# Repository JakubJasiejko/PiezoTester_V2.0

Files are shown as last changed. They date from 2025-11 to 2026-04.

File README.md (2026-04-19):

# PiezoTester V2.0

PiezoTester V2.0 is a custom mechatronic test platform for piezoresistive and piezoelectric sensor evaluation under repeatable electromagnetic loading. The project combines an ESP32-based real-time firmware stack, a desktop control application, custom electronics, and mechanical fixtures into one reproducible research toolchain.

It is not just a “demo rig”. It is a full test bench with closed-loop load estimation, sensor-path calibration, adaptive electromagnet characterization, automated reporting, and hardware revision tracking.

## Why This Repository Matters

PiezoTester V2.0 was built to make experimental work faster, cleaner, and more defensible:

- Repeatable cyclic load generation using an electromagnet-driven actuator
- Real-time acquisition of load-cell and piezoresistive sensor data
- Calibration workflows aligned with the actual firmware implementation
- Adaptive PWM-to-load learning for feedforward-assisted ramp tests
- Standard, ramp, and hysteresis test modes
- Desktop export pipeline for CSV and PDF reports
- Versioned PCB and CAD assets kept next to the code that drives them

## Project Structure

```text
PiezoTester_V2.0/
├── firmware/         ESP32 firmware (ESP-IDF, C)
├── desktop_app/      Desktop control and reporting application (Python, PySide6)
├── hardware/
│   ├── PCB/          KiCad projects, board revisions, fabrication outputs
│   └── CAD/          Mechanical CAD parts and assemblies
├── sample_results/   Example CSV/PDF outputs generated by the system
├── docs/             Cross-project documentation, asset sources, image placeholders
├── LICENSE
└── README.md
```

## Core Features

- Multi-mode testing: standard, ramp, and hysteresis acquisition
- One-point load-cell calibration with nominal model correction
- Sensor-path resistance calibration using a reference resistor
- Continuous live mass preview in the calibration workflow
- Advanced electromagnet contact calibration with stored contact-state tables
- Learned PWM-to-load map with point insertion, sorting, interpolation, and reuse
- Feedforward-assisted ramp control with bounded correction steps
- Automatic test summary generation with CSV/PDF export support
- Hardware revision history covering PCB and mechanical development

## Technical Highlights

- Nominal load-cell model based on beam capacity, sensitivity, excitation voltage, and analog gain
- Absolute-value load signal handling to avoid negative mass artifacts
- Resistance reconstruction from divider voltage with a calibration factor stored in NVS
- Electromagnet premodel derived from movement/contact thresholds
- Learned actuator model stored as empirical `(PWM, mass)` pairs
- Piecewise-linear feedforward estimate for ramp tests
- Iterative predictive-corrective update in the ramp controller
- Burst acquisition for hysteresis traces at high sample rate

## Recent Project Wins

- A research-grade calibration flow that mirrors the actual firmware math
- On-device learning of electromagnet behavior instead of fixed lookup-only control
- Integrated desktop reporting that produces presentation-ready PDF summaries
- Multiple PCB revisions with local symbol, footprint, and 3D asset preservation
- A repository structure now being shaped to support publication, fabrication, and onboarding

## Visuals

Add your best visuals here and the repository will immediately look much more “product-level”.

### Hero Shot

PiezoTester hero shot

_Suggested image: full assembled device on bench, powered on, with the desktop UI visible in the background._

### Desktop Application

Desktop application screenshot

_Suggested image: the main control window with charts, statistics, and connection status._

### PCB Render

PCB render

_Suggested image: 3D render of the latest board revision in KiCad._

### Mechanical Assembly

Mechanical assembly

_Suggested image: CAD assembly or the real fixture with the load cell, electromagnet, and specimen stage._

## Getting Started

### Firmware

See [firmware/README.md](firmware/README.md) for build, flash, and architecture details.

### Desktop Application

See [desktop_app/README.md](desktop_app/README.md) for runtime requirements, launch instructions, and export workflow notes.

### Hardware

See:

- [hardware/README.md](hardware/README.md)
- [hardware/PCB/README.md](hardware/PCB/README.md)
- [hardware/CAD/README.md](hardware/CAD/README.md)

## Asset Sources and Dependencies

The repository intentionally keeps third-party footprint/model provenance visible instead of burying it in tool-generated files.

See:

- [docs/README.md](docs/README.md)
- [docs/THIRD_PARTY_SOURCES.md](docs/THIRD_PARTY_SOURCES.md)

## Sample Outputs

Representative test artifacts are stored in [sample_results/README.md](sample_results/README.md).

## Self-Praise, Because It Is Earned

This project is a serious piece of interdisciplinary work:

- Embedded systems
- measurement engineering
- mechatronic actuation
- hardware design
- desktop tooling
- experimental workflow design

That combination is hard to execute well, and PiezoTester V2.0 already shows a lot more systems thinking than a typical “lab side-project”. It deserves to look the part.

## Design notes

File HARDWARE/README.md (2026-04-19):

# Hardware

This directory contains the physical implementation of PiezoTester V2.0: electronics, PCB revisions, and mechanical CAD.

## Scope

- Measurement electronics
- Actuator-drive electronics
- PCB revision history
- Local KiCad symbol, footprint, and 3D assets
- Mechanical fixture and assembly parts

## Subdirectories

- [PCB/README.md](PCB/README.md)
  KiCad projects, fabrication outputs, local libraries, and revision-specific notes.
- [CAD/README.md](CAD/README.md)
  Mechanical parts and assembly files used to build the test fixture.

## Design Philosophy

The hardware side of this repository is treated as a first-class engineering asset rather than a binary dump. Board revisions, local libraries, and CAD files are intentionally kept close to the firmware and desktop software so the full system stays reproducible.

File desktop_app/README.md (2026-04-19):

# Desktop Application

This directory contains the host-side control software for PiezoTester V2.0. The application is written in Python with PySide6 and acts as the main user interface for calibration, live monitoring, test execution, charting, and report export.

## Features

- Serial-device discovery and connection handling
- Live mass preview during calibration
- Standard, ramp, and hysteresis test control
- Electromagnet advanced calibration workflows
- Interactive result tables and multi-chart views
- CSV export for raw session data
- PDF export for polished experiment summaries
- Optional operator notes included in the generated report

## Runtime Dependencies

- Python 3.11+
- PySide6
- pyserial

Install the dependencies with:

```bash
cd desktop_app
python3 -m venv .venv
source .venv/bin/activate
pip install -r requirements.txt
```

## Launch

```bash
cd desktop_app
python3 main.py
```

## Important Subfolders

- `logs/`
  Local session outputs generated during development and bench testing.
- `.venv/`
  Local virtual environment, intentionally ignored by Git.
- `.idea/`
  Local IDE metadata, intentionally ignored by Git.

## Notes

- The application expects the ESP32 firmware UART protocol defined in `firmware/main/main.c`.
- Exported reports are intentionally stored as regular files so they can be attached to experiments, papers, and manufacturing validation records.

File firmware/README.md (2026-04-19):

# Firmware

This directory contains the ESP32 firmware for PiezoTester V2.0. It is built with ESP-IDF and implements the real-time measurement, calibration, electromagnet control, session logic, and UART command interface used by the desktop application.

## What This Firmware Does

- Reads the ADS1219-based load path
- Reconstructs piezoresistive sensor resistance
- Calibrates the load cell and the sensor path
- Drives the electromagnet through PWM
- Learns an empirical PWM-to-load model
- Executes standard, ramp, and hysteresis tests
- Stores calibration data and learned model points in NVS
- Streams results and status to the host application over UART

## Key Capabilities

- Load preview with automatic tare initialization
- One-point load-cell calibration with nominal-model correction
- Reference-resistor calibration for the sensor measurement path
- Contact-threshold and movement-threshold learning for the electromagnet
- Adaptive ramp targeting with feedforward plus bounded correction
- Hysteresis trace acquisition at high sample rate
- Export-friendly UART protocol for the desktop application

## Main Source Files

```text
firmware/
├── CMakeLists.txt
├── sdkconfig
└── main/
    ├── main.c        Application logic, test controller, calibration, learning
    ├── ads1219.c/h   ADS1219 ADC driver
    ├── i2c.c/h       I2C transport helpers
    ├── uart.c/h      UART transport helpers
    ├── spi.c/h       SPI helpers used by board support code
    └── adg731.c/h    ADG731 channel switch helper
```

## Build

```bash
cd firmware
idf.py build
```

## Flash

```bash
cd firmware
idf.py -p /dev/ttyUSB0 flash monitor
```

Adjust the serial port to match your machine.

## Firmware Architecture

The firmware centers around three coupled subsystems:

1. Measurement subsystem
   Captures load and sensor-path voltages, converts them to calibrated engineering units, and returns structured test results.

2. Calibration and learning subsystem
   Maintains load-cell calibration, sensor-path calibration, electromagnet thresholds, and the learned PWM-to-load map in NVS.

3. Test execution subsystem
   Runs measurement sessions in standard, ramp, and hysteresis modes while keeping the UART interface deterministic for the desktop application.

## Mathematical / Algorithmic Notes

- Load signal is computed from the absolute difference between zero and measured voltage.
- Load-cell calibration uses a nominal physical model corrected by a one-point scaling factor.
- Sensor resistance is reconstructed from divider voltage and corrected by a calibration factor.
- Ramp control uses:
  - a feedforward estimate from the learned actuator model
  - an iterative correction loop with bounded PWM step size
- Hysteresis acquisition uses burst-style high-rate sampling across loading and unloading phases.

## Documentation Quality

The firmware headers and main application source are being annotated with Doxygen-style comments so the codebase can be turned into browsable technical documentation later.

## Notes About Legacy / Generated Files

This repository has been actively used during hardware bring-up. Some generated or legacy files still exist for traceability, but they are now documented and increasingly fenced off by `.gitignore` rules and folder-level README files.

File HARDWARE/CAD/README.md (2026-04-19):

# CAD

This directory contains the mechanical design assets for PiezoTester V2.0.

## Contents

- SolidWorks part files (`.SLDPRT`)
- SolidWorks assembly files (`.SLDASM`)
- STEP exports for exchange and review

## Typical Parts

- Electromagnet mounting hardware
- Structural profiles and fixture supports
- Table / specimen support geometry
- Load-cell support parts
- Contact and pressure-transfer parts

## Intent

The CAD side of the project documents how the electrical and sensing stack is physically realized. These files are essential to understanding:

- specimen alignment
- force transmission path
- load-cell mounting
- electromagnet positioning
- fixture repeatability

## Exchange-Friendly Files

Where STEP files are present, they should be treated as the preferred review / sharing format for collaborators who do not use SolidWorks.

## Local Authoring Note

Most files in this folder are project-authored mechanical assets rather than third-party vendor downloads. When a neutral exchange export exists, it is kept next to the native CAD source on purpose.

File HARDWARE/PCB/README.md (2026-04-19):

# PCB

This directory stores the electrical design history of PiezoTester V2.0 in KiCad.

## Available Revisions

- `PCB V2.0`
  Early board revision and legacy project assets.
- `PCB V2.1`
  Intermediate revision with local 3D model integration.
- `PCB V2.2`
  Later revision with fabrication outputs and local symbol / footprint libraries.

## What You Will Find Here

- `.kicad_pro`, `.kicad_sch`, `.kicad_pcb` source files
- Local symbol and footprint libraries
- Local 3D models used by KiCad
- Gerber exports and production artifacts
- Revision-specific backup archives generated by KiCad

## Source Provenance

This repository mixes:

- custom project-specific KiCad symbols and footprints
- vendor-derived assets from SamacSys-style libraries
- SparkFun and Espressif-derived reference models for selected modules
- local fixes applied so 3D models resolve directly from the repository

See [../../docs/THIRD_PARTY_SOURCES.md](../../docs/THIRD_PARTY_SOURCES.md) for the documented origin of the main assets.

## Practical Note

KiCad creates autosaves, lock files, cache files, and backups aggressively during active design sessions. The repository now documents these artifacts explicitly and ignores the transient ones where possible, while preserving revision history that is actually useful.

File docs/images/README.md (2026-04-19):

# README Image Placeholders

Place repository-facing visuals here.

Recommended files:

- `hero-shot.jpg`
- `desktop-app-screenshot.png`
- `pcb-render.png`
- `mechanical-assembly.png`

These names are already referenced by the top-level `README.md`.

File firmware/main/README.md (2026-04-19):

# Firmware Main Module

This folder contains the application-layer firmware sources for PiezoTester V2.0.

## File Responsibilities

- `main.c`
  High-level application logic, calibration workflow, test execution, UART command handling, actuator learning, and NVS persistence
- `ads1219.c/h`
  ADS1219 ADC transport and conversion control
- `i2c.c/h`
  I2C bus helper layer
- `uart.c/h`
  UART helper layer
- `spi.c/h`
  SPI helper layer used by board support code
- `adg731.c/h`
  ADG731 switching helper

## Documentation Style

This folder is being annotated with Doxygen-style comments so the firmware can later be published as browsable API / implementation documentation.

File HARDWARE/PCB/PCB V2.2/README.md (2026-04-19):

# PCB V2.2

This folder contains a later and more production-oriented board revision for PiezoTester V2.0.

## Highlights

- Expanded local footprint and symbol libraries
- Local 3D model assets kept inside the repository
- Fabrication outputs for manufacturing
- JLCPCB BOM / CPL generation support

## Main Project Path

- `piezoTester v2.2/piezoTester v2.2.kicad_pro`

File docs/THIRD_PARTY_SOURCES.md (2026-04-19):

# Third-Party Sources and Dependency Notes

This document records the main external building blocks used in PiezoTester V2.0 so the repository stays traceable and publication-friendly.

## Firmware Dependencies

### ESP-IDF

- Role: primary embedded framework for ESP32 firmware
- Usage: GPIO, LEDC PWM, UART, I2C, SPI, NVS, timing, FreeRTOS integration
- Project location: `firmware/`

The firmware currently uses ESP-IDF-native drivers and in-repo application code. There are no separate Git submodules for third-party C libraries in active use at the moment.

## Desktop Application Dependencies

### PySide6

- Role: GUI framework for charts, dialogs, tables, PDF generation, and plotting UI
- Project location: `desktop_app/main.py`

### pyserial

- Role: serial communication with the ESP32 firmware
- Project location: `desktop_app/main.py`

## PCB Libraries and Model Sources

### SamacSys-generated libraries

Several local KiCad symbol / footprint libraries clearly identify themselves with:

- `generator SamacSys_ECAD_Model`

These are used in multiple board revisions and vendor-part library folders, including parts such as:

- LM358P
- MCP6002-I/P
- LM2596S-5.0/NOPB
- LP2950-33LPRE3
- ADS1219IPWR
- CP2102N
- ESP32-WROOM module libraries

These assets are kept locally so the PCB project remains portable and self-contained.

### SparkFun ADS1219 reference material

The repository also uses ADS1219-related reference geometry derived from the SparkFun Qwiic ADC ADS1219 board ecosystem for modeling / representation purposes.

### Espressif reference assets

ESP32-related 3D and module assets were aligned using Espressif reference materials and repository-local model files where required.

### Local project-specific assets

Some 3D files, symbol libraries, and KiCad project libraries were authored or adjusted directly inside the project so that:

- board renders open without missing 3D files
- library dependencies remain repository-local
- revision snapshots stay reproducible

## CAD Sources

The mechanical CAD folder primarily contains project-authored SolidWorks models plus exchange-friendly STEP exports created during device design and fixture iteration.

## Fabrication / Production Outputs

Some PCB revisions contain fabrication-ready exports such as:

- Gerber archives
- drill files
- JLCPCB BOM / CPL outputs

Those files are treated as build artifacts for manufacturing, not as the canonical source. The canonical source remains the KiCad project for the relevant board revision.

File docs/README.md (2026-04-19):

# Documentation

This directory groups repository-level documentation that does not belong to a single code or hardware subfolder.

## Included Documents

- `THIRD_PARTY_SOURCES.md`
  Source provenance for firmware dependencies, PCB assets, and 3D models
- `images/`
  Placeholder location for README visuals and publication-supporting screenshots

## Goal

Make the project easier to:

- present
- publish
- hand off
- review
- reproduce

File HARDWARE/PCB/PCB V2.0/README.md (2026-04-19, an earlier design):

# PCB V2.0

This folder contains an early KiCad revision of the PiezoTester electronics.

## Notes

- Useful as a historical design reference
- Contains local part libraries and early fabrication artifacts
- Includes KiCad-generated backups and autosave traces from active iteration

## Canonical Files

- `urzadzenie_badawcze_V2.kicad_pro`
- `urzadzenie_badawcze_V2.kicad_sch`
- `urzadzenie_badawcze_V2.kicad_pcb`

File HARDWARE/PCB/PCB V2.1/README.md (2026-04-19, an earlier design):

# PCB V2.1

This folder contains the intermediate PiezoTester PCB revision centered on the `piezotesterV2.1` KiCad project.

## Highlights

- Local 3D model integration for board visualization
- Project-local symbol assets
- Gerber export snapshots
- KiCad revision backups

## Main Project Path

- `piezotesterV2.1/piezotesterV2.1.kicad_pro`

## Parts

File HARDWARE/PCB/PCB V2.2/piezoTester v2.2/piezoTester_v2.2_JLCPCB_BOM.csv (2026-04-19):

Comment | Designator | Footprint | LCSC Part # | Quantity | Manufacturer | Manufacturer Part Number | JLC Footprint | Mouser Part Number
LED | 3V3_LED1 | LED_SMD:LED_1206_3216Metric_Pad1.42x1.75mm_HandSolder |  | 1
Barrel_Jack | 12VDC_IN1 | Connector_BarrelJack:BarrelJack_Wuerth_694108106102_2.5x5.5mm |  | 1
R 0 | AIN3 | Resistor_SMD:R_0603_1608Metric_Pad0.98x0.95mm_HandSolder |  | 1
C 22uF | C3 | Capacitor_SMD:C_1206_3216Metric_Pad1.33x1.80mm_HandSolder |  | 1
C 100nF | C4,C6,C10,C12,C28 | Capacitor_SMD:C_1206_3216Metric_Pad1.33x1.80mm_HandSolder |  | 5
C 10uF | C5 | Capacitor_SMD:C_1206_3216Metric_Pad1.33x1.80mm_HandSolder |  | 1
C 1uF | C7,C33 | Capacitor_SMD:C_1206_3216Metric_Pad1.33x1.80mm_HandSolder |  | 2
C 100nF | C8,C14,C16,C17,C20 | Capacitor_SMD:C_0603_1608Metric_Pad1.08x0.95mm_HandSolder |  | 5
C 10uF | C9 | Capacitor_SMD:C_0603_1608Metric_Pad1.08x0.95mm_HandSolder |  | 1
C 1uF | C15,C18,C19,C21 | Capacitor_SMD:C_0603_1608Metric_Pad1.08x0.95mm_HandSolder |  | 4
C 0.1 uF | C22,C23,C24,C25,C26 | Capacitor_SMD:C_0603_1608Metric_Pad1.08x0.95mm_HandSolder |  | 5
C 0.1 uF | C27,C29,C30 | Capacitor_SMD:C_1206_3216Metric_Pad1.33x1.80mm_HandSolder |  | 3
C 1 uF | C31,C32 | Capacitor_SMD:C_0603_1608Metric_Pad1.08x0.95mm_HandSolder |  | 2
ESP32-WROOM-32UE-N16 | ESP32 | 000:ESP32WROOM32UEN16 |  | 1 | Espressif Systems | ESP32-WROOM-32UE-N16
LM2596S-5.0_NOPB | IC3 | ADS1115_Salamon:KTT0005B |  | 1 | Texas Instruments | LM2596S-5.0/NOPB |  | 926-LM2596S-5.0/NOPB
ADS1219IPWR | IC5 | 000:ads1219 |  | 1 | Texas Instruments | ADS1219IPWR |  | 595-ADS1219IPWR
L 68 uH | L1 | Inductor_SMD:L_12x12mm_H6mm |  | 1
R 1K | R2,R3,R20,R22,R23 | Resistor_SMD:R_1206_3216Metric_Pad1.30x1.75mm_HandSolder |  | 5
R 62K | R4,R5 | Resistor_SMD:R_1206_3216Metric_Pad1.30x1.75mm_HandSolder |  | 2
R 1k | R9 | Resistor_SMD:R_1206_3216Metric_Pad1.30x1.75mm_HandSolder |  | 1
R 4.7K | R10 | Resistor_SMD:R_1206_3216Metric_Pad1.30x1.75mm_HandSolder |  | 1
R 10K | R11,R12 | Resistor_SMD:R_1206_3216Metric_Pad1.30x1.75mm_HandSolder |  | 2
R 22 | R13,R14 | Resistor_SMD:R_1206_3216Metric_Pad1.30x1.75mm_HandSolder |  | 2
R 4.7K | R18,R19 | Resistor_SMD:R_0603_1608Metric_Pad0.98x0.95mm_HandSolder |  | 2
R 200K | R21 | Resistor_SMD:R_1206_3216Metric_Pad1.30x1.75mm_HandSolder |  | 1
R 1 | R24 | Resistor_SMD:R_0603_1608Metric_Pad0.98x0.95mm_HandSolder |  | 1
R 680 | R25 | Resistor_SMD:R_1206_3216Metric_Pad1.30x1.75mm_HandSolder |  | 1
R 1 | R26,R27,R28,R29 | Resistor_SMD:R_1206_3216Metric_Pad1.30x1.75mm_HandSolder |  | 4
CH340C | U1 | Package_SO:SOIC-16_3.9x9.9mm_P1.27mm |  | 1

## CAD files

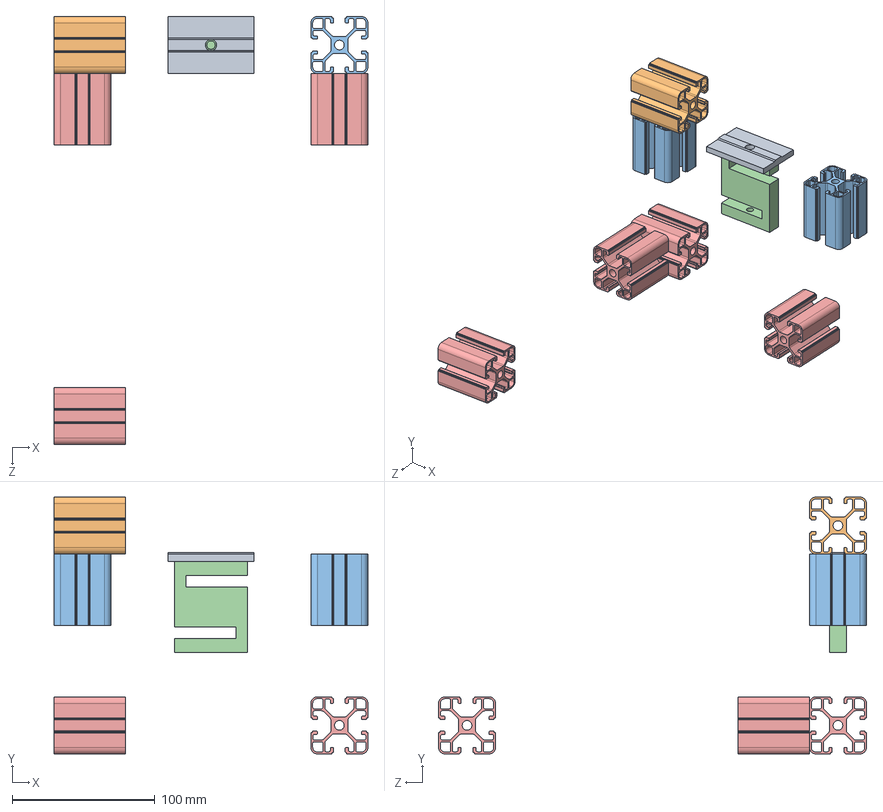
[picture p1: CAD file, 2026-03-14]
HARDWARE/CAD/Złożenie1.SLDASM
220.0 x 180.0 x 300.0 mm
profil_300 x 4
belka_h3C3
profil_rama x 2
profil_nawiercony
stabilizator_belki

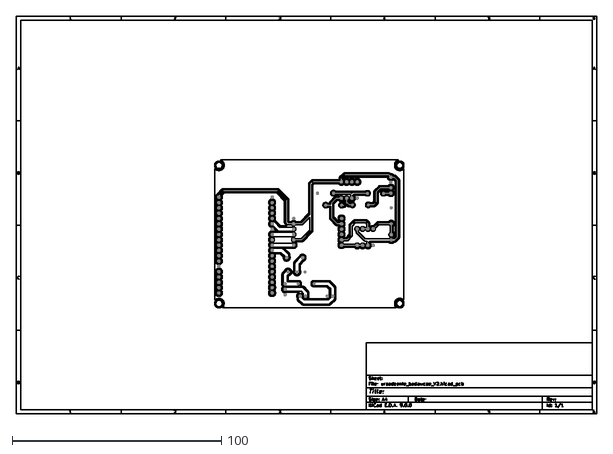
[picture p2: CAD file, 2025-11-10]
firmware/hardware/urzadzenie_badawcze_V2/pcb/urzadzenie_badawcze_V2-F_Cu.dxf
277.0 x 190.0

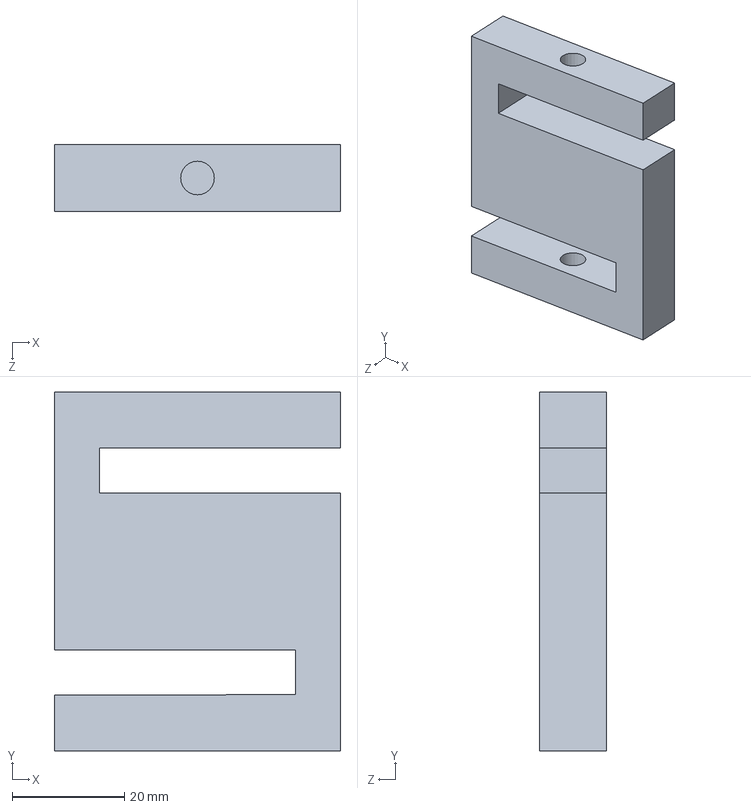
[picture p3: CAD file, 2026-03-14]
HARDWARE/CAD/belka_h3C3.SLDPRT
51.0 x 64.0 x 12.0 mm

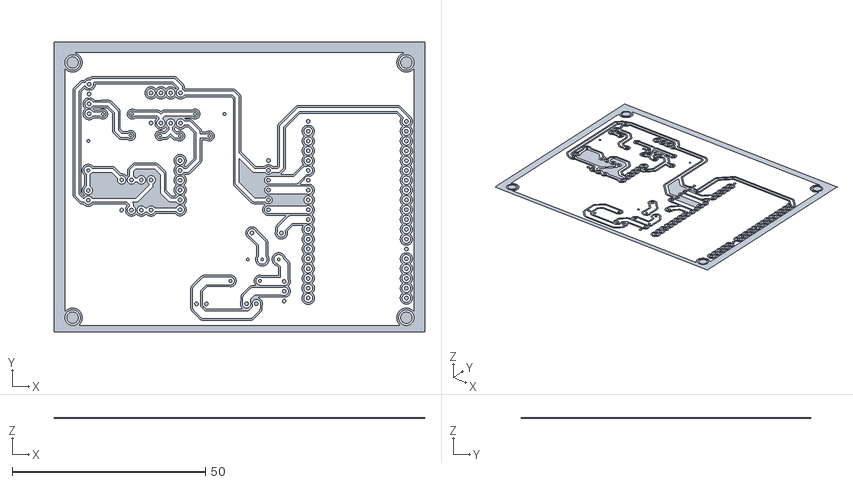
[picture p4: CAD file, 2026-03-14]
hardware/PCB/PCB V2.2/piezoTester v2.2/stl/urzadzenie_badawcze_V2-F_Cu-GOOD.stl
96.0 x 75.0 x 0.05

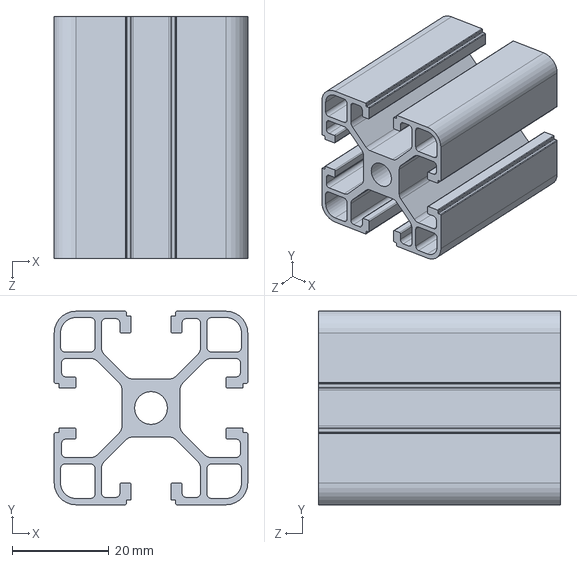
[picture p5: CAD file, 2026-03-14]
HARDWARE/CAD/profil_rama.SLDPRT
40.0 x 40.0 x 50.0 mm

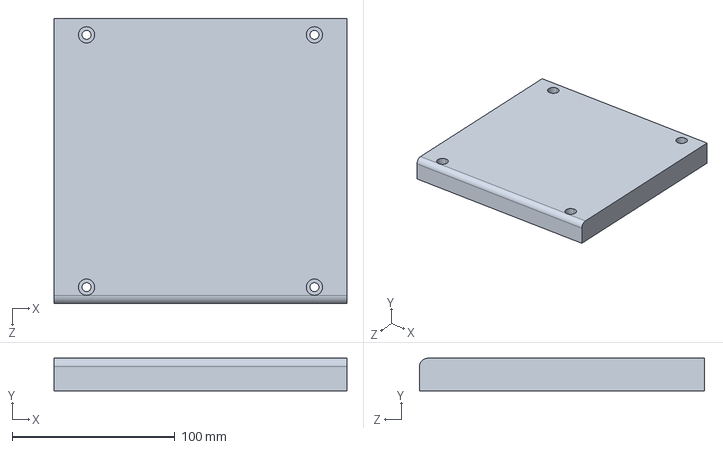
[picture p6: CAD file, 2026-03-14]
HARDWARE/CAD/stolik.STEP
180.0 x 20.0 x 175.0 mm

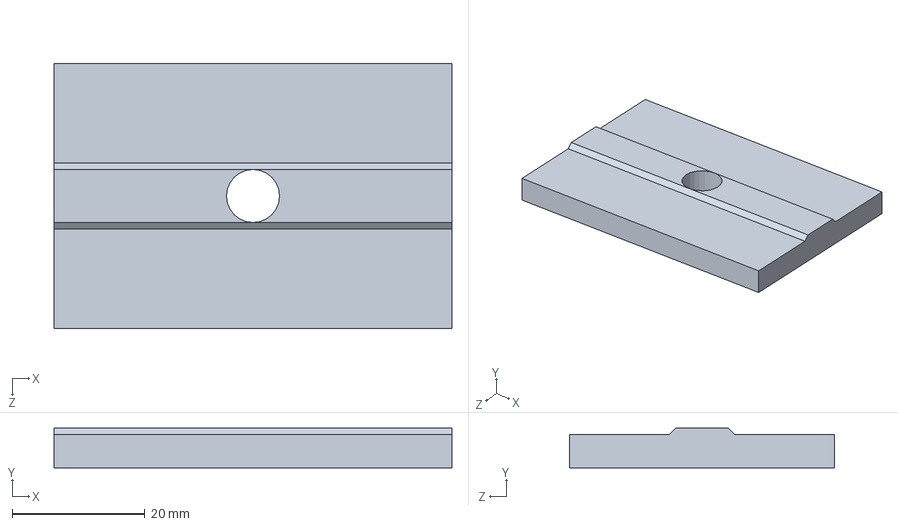
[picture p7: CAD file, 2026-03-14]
HARDWARE/CAD/stabilizator_belki.SLDPRT
60.0 x 6.00 x 40.0 mm

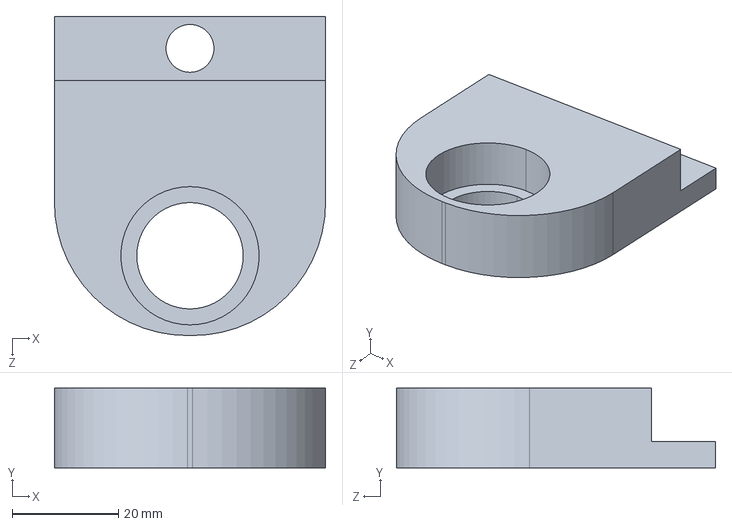
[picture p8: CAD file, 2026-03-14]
HARDWARE/CAD/mocowanie elektromagnesu ofc.STEP
51.0 x 15.0 x 60.0 mm

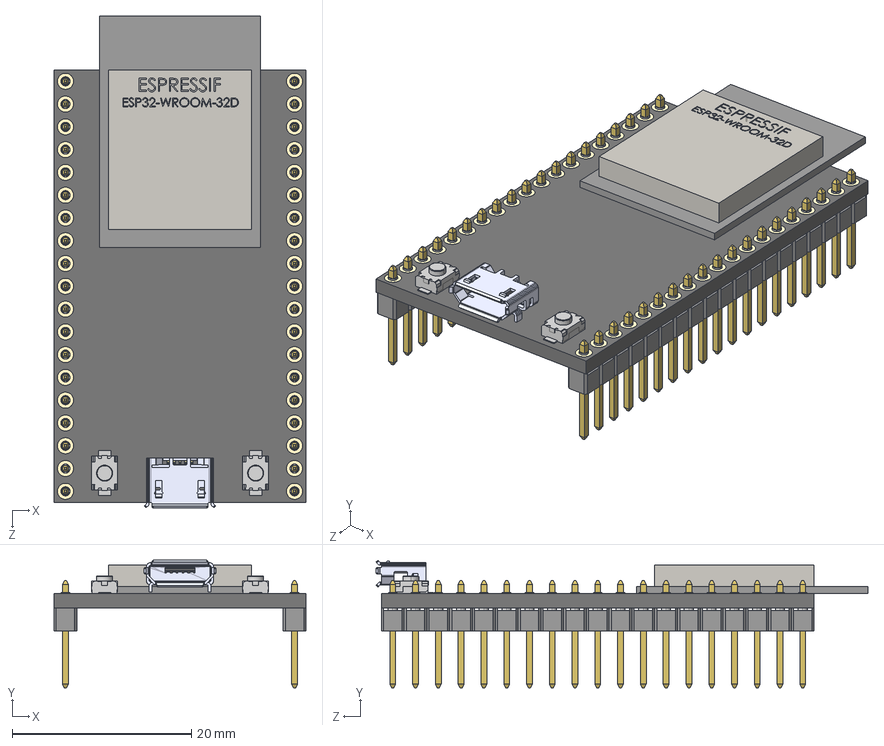
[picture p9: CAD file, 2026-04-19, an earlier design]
HARDWARE/PCB/PCB V2.1/piezotesterV2.1/3dmodels/ESP32-WROOM-32D-Assembly.STEP
28.1 x 14.2 x 54.9 mm
Main-PCB
zl201-19_p2-54_l48-3_w2-54_h8-9 x 2
Soldering-Contacts
ab2_usb_micro_smd.wrl
ESP32-chip
3x4x2mm_tact_button x 2

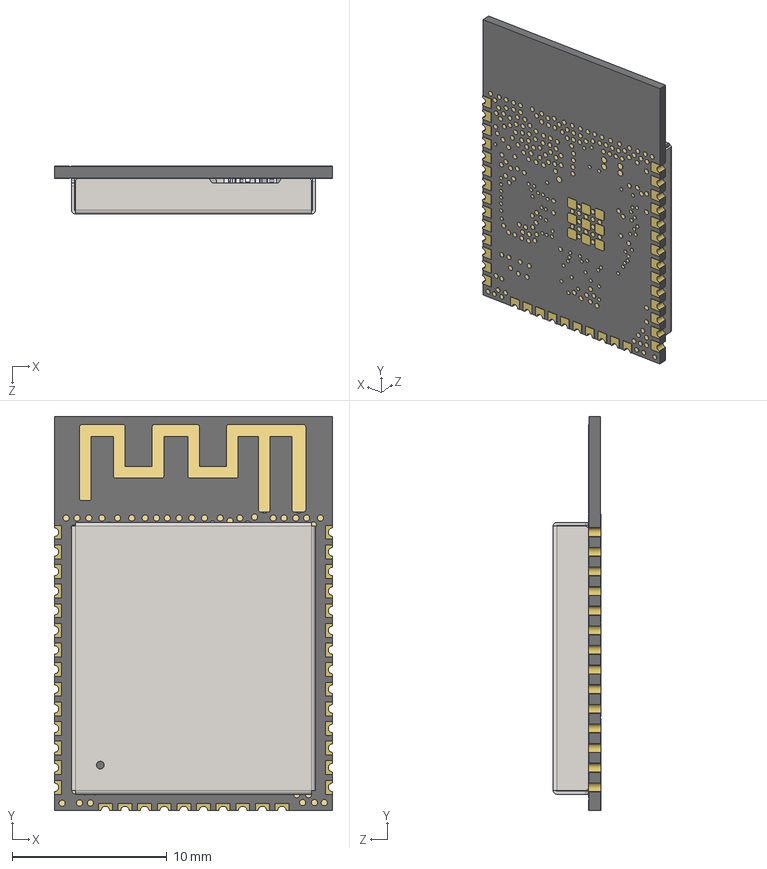
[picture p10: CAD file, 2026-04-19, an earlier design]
HARDWARE/PCB/PCB V2.1/piezotesterV2.1/3dmodels/ESP32-WROOM-32E.STEP
18.0 x 25.5 x 3.10 mm
ESP32_5x5_20210301.STEP^ESP32_5x5_20210301.STEP_Submodel-SLP48_5X5_part_DesignRootModel_PCB_ESP32-WROOM-32E_V1(2)_PCB_ESP32-WROOM-32E_V1
trace_1^Submodel-ANT_L_TYPEA_1501846164_part_DesignRootModel_PCB_ESP32-WROOM-32E_V1(2)_PCB_ESP32-WROOM-32E_V1
DFN1006.STEP^DFN1006.STEP_Submodel-SOD882_part_DesignRootModel_PCB_ESP32-WROOM-32E_V1(2)_PCB_ESP32-WROOM-32E_V1
R0201_20210301.STEP^R0201_20210301.STEP_Submodel-R0201_part_DesignRootModel_PCB_ESP32-WROOM-32E_V1(2)_PCB_ESP32-WROOM-32E_V1 x 3
L0201_20210301.STEP^L0201_20210301.STEP_Submodel-L0201_part_DesignRootModel_PCB_ESP32-WROOM-32E_V1(2)_PCB_ESP32-WROOM-32E_V1 x 2
C0201_20210301.STEP^C0201_20210301.STEP_Submodel-C0201_part_DesignRootModel_PCB_ESP32-WROOM-32E_V1(2)_PCB_ESP32-WROOM-32E_V1 x 17
SOIC8_208_20210301.STEP^SOIC8_208_20210301.STEP_Submodel-SOIC08-WN_part_DesignRootModel_PCB_ESP32-WROOM-32E_V1(2)_PCB_ESP32-WROOM-32E_V1
XTAL3225_20210301.STEP^XTAL3225_20210301.STEP_Submodel-3225_part_DesignRootModel_PCB_ESP32-WROOM-32E_V1(2)_PCB_ESP32-WROOM-32E_V1
C0402_20210301.STEP^C0402_20210301.STEP_Submodel-0402A_part_DesignRootModel_PCB_ESP32-WROOM-32E_V1(2)_PCB_ESP32-WROOM-32E_V1 x 2
uid__1-311^DesignRootModel_PCB_ESP32-WROOM-32E_V1(2)_PCB_ESP32-WROOM-32E_V1
uid__1-312^DesignRootModel_PCB_ESP32-WROOM-32E_V1(2)_PCB_ESP32-WROOM-32E_V1
uid__1-313^DesignRootModel_PCB_ESP32-WROOM-32E_V1(2)_PCB_ESP32-WROOM-32E_V1
uid__1-314^DesignRootModel_PCB_ESP32-WROOM-32E_V1(2)_PCB_ESP32-WROOM-32E_V1
uid__1-315^DesignRootModel_PCB_ESP32-WROOM-32E_V1(2)_PCB_ESP32-WROOM-32E_V1
uid__1-316^DesignRootModel_PCB_ESP32-WROOM-32E_V1(2)_PCB_ESP32-WROOM-32E_V1
uid__1-317^DesignRootModel_PCB_ESP32-WROOM-32E_V1(2)_PCB_ESP32-WROOM-32E_V1
uid__1-318^DesignRootModel_PCB_ESP32-WROOM-32E_V1(2)_PCB_ESP32-WROOM-32E_V1
uid__1-319^DesignRootModel_PCB_ESP32-WROOM-32E_V1(2)_PCB_ESP32-WROOM-32E_V1
uid__1-320^DesignRootModel_PCB_ESP32-WROOM-32E_V1(2)_PCB_ESP32-WROOM-32E_V1
uid__1-321^DesignRootModel_PCB_ESP32-WROOM-32E_V1(2)_PCB_ESP32-WROOM-32E_V1
uid__1-322^DesignRootModel_PCB_ESP32-WROOM-32E_V1(2)_PCB_ESP32-WROOM-32E_V1
uid__1-323^DesignRootModel_PCB_ESP32-WROOM-32E_V1(2)_PCB_ESP32-WROOM-32E_V1
uid__1-324^DesignRootModel_PCB_ESP32-WROOM-32E_V1(2)_PCB_ESP32-WROOM-32E_V1
uid__1-325^DesignRootModel_PCB_ESP32-WROOM-32E_V1(2)_PCB_ESP32-WROOM-32E_V1
uid__1-326^DesignRootModel_PCB_ESP32-WROOM-32E_V1(2)_PCB_ESP32-WROOM-32E_V1
uid__1-327^DesignRootModel_PCB_ESP32-WROOM-32E_V1(2)_PCB_ESP32-WROOM-32E_V1
uid__1-328^DesignRootModel_PCB_ESP32-WROOM-32E_V1(2)_PCB_ESP32-WROOM-32E_V1
uid__1-329^DesignRootModel_PCB_ESP32-WROOM-32E_V1(2)_PCB_ESP32-WROOM-32E_V1
uid__1-330^DesignRootModel_PCB_ESP32-WROOM-32E_V1(2)_PCB_ESP32-WROOM-32E_V1
uid__1-331^DesignRootModel_PCB_ESP32-WROOM-32E_V1(2)_PCB_ESP32-WROOM-32E_V1
uid__1-332^DesignRootModel_PCB_ESP32-WROOM-32E_V1(2)_PCB_ESP32-WROOM-32E_V1
uid__1-333^DesignRootModel_PCB_ESP32-WROOM-32E_V1(2)_PCB_ESP32-WROOM-32E_V1
uid__1-334^DesignRootModel_PCB_ESP32-WROOM-32E_V1(2)_PCB_ESP32-WROOM-32E_V1
uid__1-335^DesignRootModel_PCB_ESP32-WROOM-32E_V1(2)_PCB_ESP32-WROOM-32E_V1
uid__1-336^DesignRootModel_PCB_ESP32-WROOM-32E_V1(2)_PCB_ESP32-WROOM-32E_V1
uid__1-337^DesignRootModel_PCB_ESP32-WROOM-32E_V1(2)_PCB_ESP32-WROOM-32E_V1
uid__1-338^DesignRootModel_PCB_ESP32-WROOM-32E_V1(2)_PCB_ESP32-WROOM-32E_V1
uid__1-339^DesignRootModel_PCB_ESP32-WROOM-32E_V1(2)_PCB_ESP32-WROOM-32E_V1
uid__1-340^DesignRootModel_PCB_ESP32-WROOM-32E_V1(2)_PCB_ESP32-WROOM-32E_V1
uid__1-341^DesignRootModel_PCB_ESP32-WROOM-32E_V1(2)_PCB_ESP32-WROOM-32E_V1
uid__1-342^DesignRootModel_PCB_ESP32-WROOM-32E_V1(2)_PCB_ESP32-WROOM-32E_V1
uid__1-343^DesignRootModel_PCB_ESP32-WROOM-32E_V1(2)_PCB_ESP32-WROOM-32E_V1
uid__1-344^DesignRootModel_PCB_ESP32-WROOM-32E_V1(2)_PCB_ESP32-WROOM-32E_V1
uid__1-345^DesignRootModel_PCB_ESP32-WROOM-32E_V1(2)_PCB_ESP32-WROOM-32E_V1
uid__1-346^DesignRootModel_PCB_ESP32-WROOM-32E_V1(2)_PCB_ESP32-WROOM-32E_V1
uid__1-347^DesignRootModel_PCB_ESP32-WROOM-32E_V1(2)_PCB_ESP32-WROOM-32E_V1
uid__1-348^DesignRootModel_PCB_ESP32-WROOM-32E_V1(2)_PCB_ESP32-WROOM-32E_V1
uid__1-349^DesignRootModel_PCB_ESP32-WROOM-32E_V1(2)_PCB_ESP32-WROOM-32E_V1
uid__1-350^DesignRootModel_PCB_ESP32-WROOM-32E_V1(2)_PCB_ESP32-WROOM-32E_V1
uid__1-351^DesignRootModel_PCB_ESP32-WROOM-32E_V1(2)_PCB_ESP32-WROOM-32E_V1
uid__1-352^DesignRootModel_PCB_ESP32-WROOM-32E_V1(2)_PCB_ESP32-WROOM-32E_V1
uid__1-353^DesignRootModel_PCB_ESP32-WROOM-32E_V1(2)_PCB_ESP32-WROOM-32E_V1
uid__1-354^DesignRootModel_PCB_ESP32-WROOM-32E_V1(2)_PCB_ESP32-WROOM-32E_V1
uid__1-355^DesignRootModel_PCB_ESP32-WROOM-32E_V1(2)_PCB_ESP32-WROOM-32E_V1
uid__1-356^DesignRootModel_PCB_ESP32-WROOM-32E_V1(2)_PCB_ESP32-WROOM-32E_V1
uid__1-357^DesignRootModel_PCB_ESP32-WROOM-32E_V1(2)_PCB_ESP32-WROOM-32E_V1
uid__1-359^DesignRootModel_PCB_ESP32-WROOM-32E_V1(2)_PCB_ESP32-WROOM-32E_V1
uid__1-360^DesignRootModel_PCB_ESP32-WROOM-32E_V1(2)_PCB_ESP32-WROOM-32E_V1
uid__1-361^DesignRootModel_PCB_ESP32-WROOM-32E_V1(2)_PCB_ESP32-WROOM-32E_V1
uid__1-362^DesignRootModel_PCB_ESP32-WROOM-32E_V1(2)_PCB_ESP32-WROOM-32E_V1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

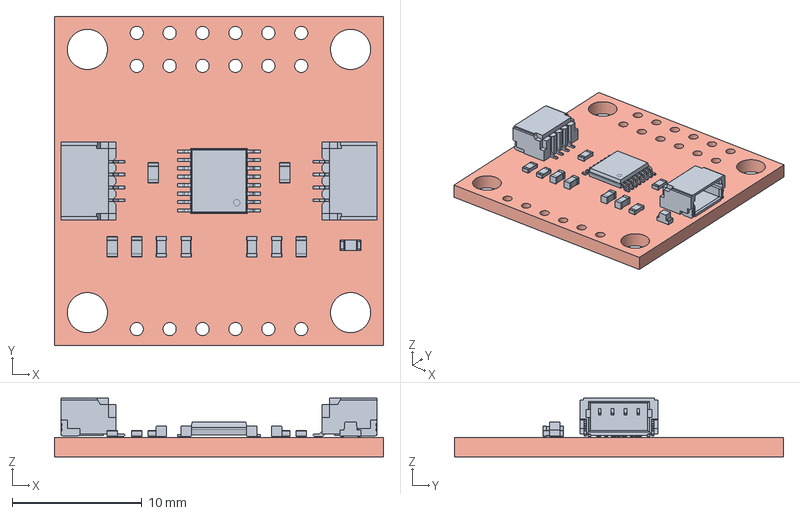
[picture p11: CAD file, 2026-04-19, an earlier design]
HARDWARE/PCB/PCB V2.1/piezotesterV2.1/3dmodels/Qwiic_ADC_ADS1219.step
25.4 x 25.4 x 4.55 mm
TSSOP-16_4.4x5mm_P0.65mm
R_0603_1608Metric x 5
C_0603_1608Metric x 4
Qwiic-Horizontal x 2
LED_0603_1608Metric_Red
Qwiic_ADC_ADS1219_PCB

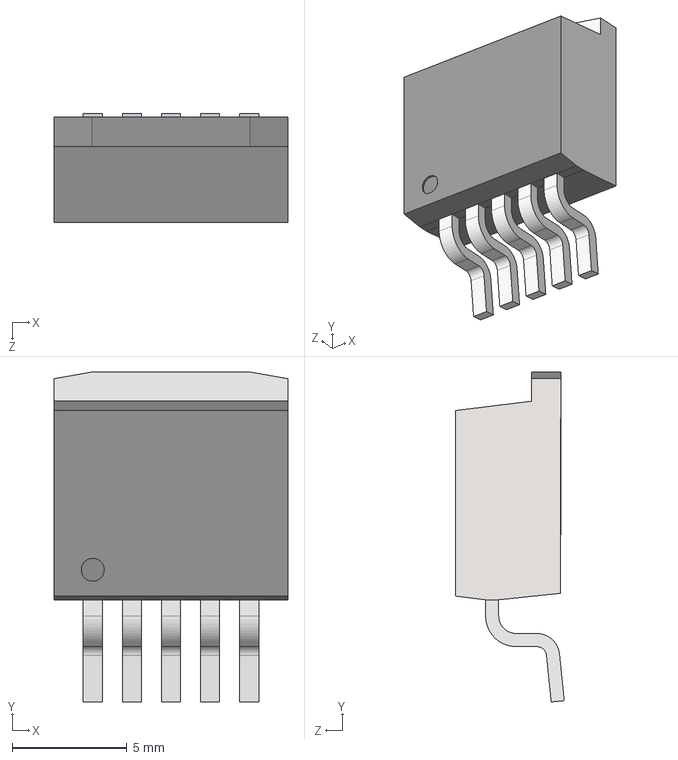
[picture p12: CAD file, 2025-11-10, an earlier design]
HARDWARE/PCB/PCB V2.1/piezotesterV2.1/3dmodels/LM2596S-5.0_NOPB.stp
10.2 x 14.3 x 4.72 mm

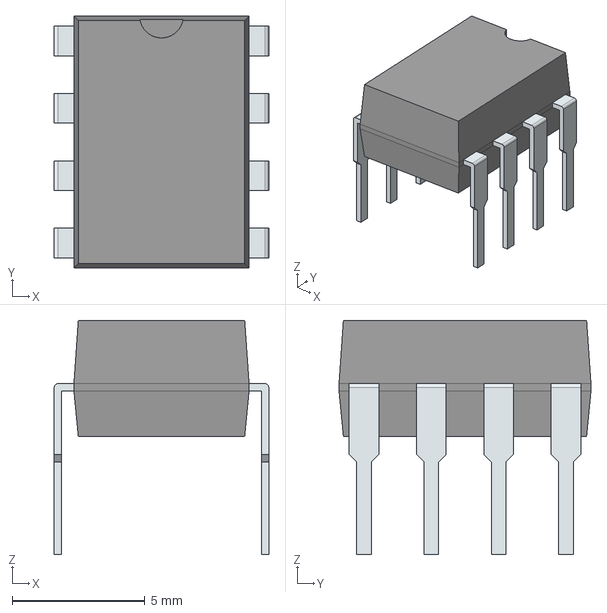
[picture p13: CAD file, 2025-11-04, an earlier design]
HARDWARE/PCB/PCB V2.1/piezotesterV2.1/3dmodels/MCP6002-I_P.stp
8.09 x 9.50 x 8.83 mm
PinsArrayLR

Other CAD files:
HARDWARE/CAD/profil_nawiercony.SLDPRT
HARDWARE/CAD/profil_300.SLDPRT
HARDWARE/CAD/4040 Aluminum Extrusion Profile.SLDPRT
HARDWARE/CAD/mocowanie elektromagnesu.STEP
HARDWARE/CAD/Część4.SLDPRT
HARDWARE/CAD/mocowanie elektromagnesu ofc.SLDPRT
HARDWARE/CAD/mocowanie elektromagnesu.SLDPRT
HARDWARE/CAD/stolik.SLDPRT

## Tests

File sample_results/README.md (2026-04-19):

# Sample Results

This directory contains representative exported artifacts generated by the desktop application during real bench testing.

## Included File Types

- `*.csv`
  Raw or session-level measurement exports
- `*.pdf`
  Human-readable reports generated by the application

## Why Keep These

These files are useful as:

- UI/export regression references
- formatting examples for future reports
- publication-supporting material
- sanity-check material for new contributors

## Recommendation

Keep this folder small and curated. It should show what a good result package looks like, not become a dump of every local experiment.

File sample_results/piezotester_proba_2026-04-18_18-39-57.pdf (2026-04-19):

# Raport proby PiezoTester V2.0

Wygenerowano: 2026-04-18 18:48:20

Data rozpoczecia
2026-04-18 18:39:57

Data zakonczenia
2026-04-18 18:47:54
Czas trwania
07:57

Liczba probek
30
Typ testu
Standardowy

## Komentarz

Próba 30 do artykułu

## Wartosci statystyczne

Parametr | Srednia | Min | Max | Odch. std.
Obciazenie [g] | 1411.814 | 1394.470 | 1454.762 | 13.156
Rezystancja | 88253.985 | 81316.359 | 100204.703 | 5228.663
Rezystancja / Nr probki

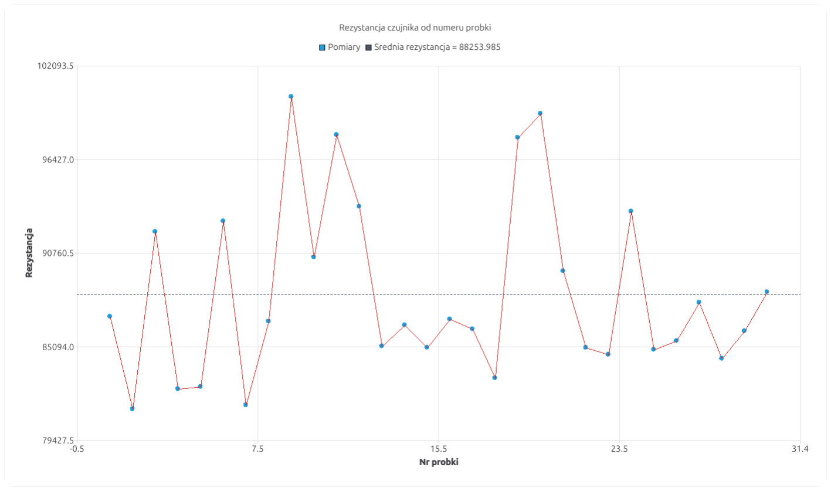
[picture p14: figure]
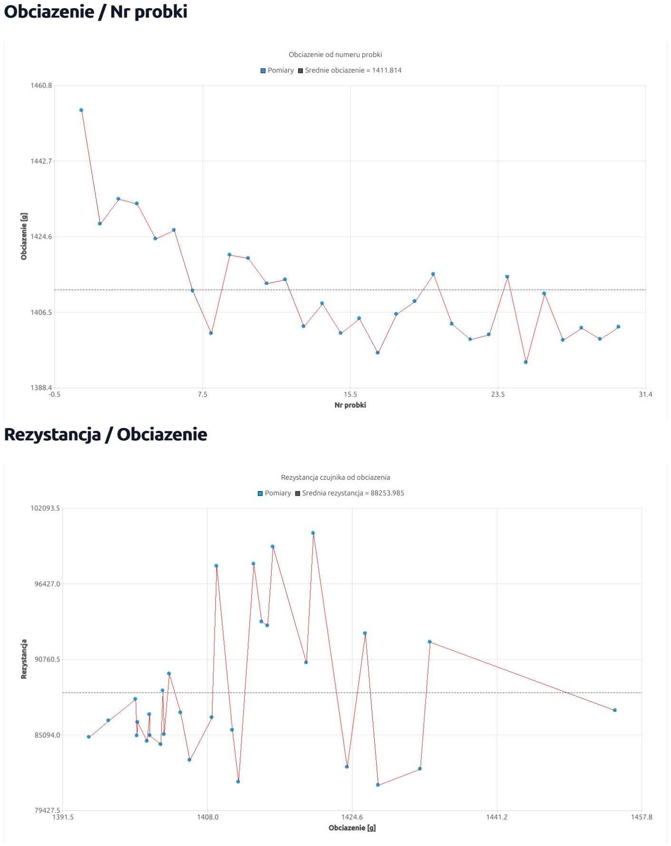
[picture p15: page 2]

Obciazenie / Nr probki

Rezystancja / Obciazenie

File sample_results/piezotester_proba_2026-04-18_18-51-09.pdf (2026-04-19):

# Raport proby PiezoTester V2.0

Wygenerowano: 2026-04-18 19:12:38

Data rozpoczecia
2026-04-18 18:51:09

Data zakonczenia
2026-04-18 19:11:28
Czas trwania
20:18

Liczba probek
27
Typ testu
Narastajacy

Obciazenie start
600.0 g
Obciazenie koniec
1000.0 g

## Komentarz

Artykuł narastające to co się ucięło

## Wartosci statystyczne

Parametr | Srednia | Min | Max | Odch. std.
Obciazenie [g] | 993.138 | 890.557 | 1062.518 | 46.910
Rezystancja | 114963.262 | 106311.945 | 127876.797 | 5360.629
Rezystancja / Nr probki

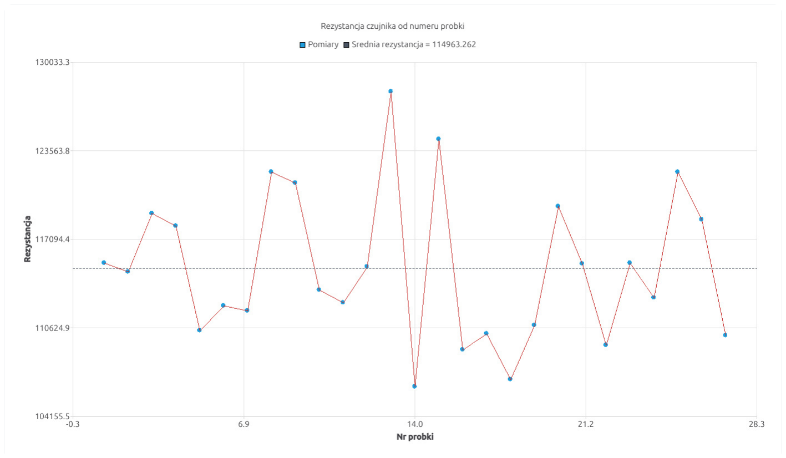
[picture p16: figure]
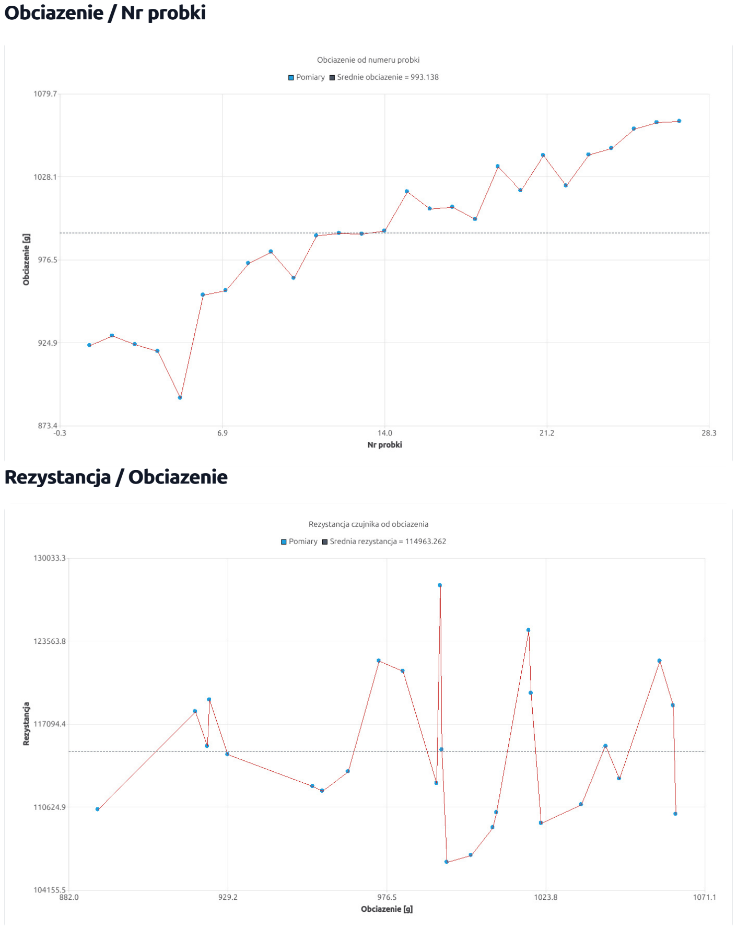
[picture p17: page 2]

Obciazenie / Nr probki

Rezystancja / Obciazenie

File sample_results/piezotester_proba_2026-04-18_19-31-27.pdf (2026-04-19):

# Raport proby PiezoTester V2.0

Wygenerowano: 2026-04-18 19:34:54

Data rozpoczecia
2026-04-18 19:31:27

Data zakonczenia
2026-04-18 19:34:37
Czas trwania
03:10

Liczba probek
10
Typ testu
Narastajacy

Obciazenie start
500.0 g
Obciazenie koniec
1180.4 g

## Komentarz

10 NARASTAJĄCY

## Wartosci statystyczne

Parametr | Srednia | Min | Max | Odch. std.
Obciazenie [g] | 850.564 | 509.100 | 1184.605 | 214.149
Rezystancja | 120677.180 | 94391.328 | 155723.438 | 20185.916
Rezystancja / Nr probki

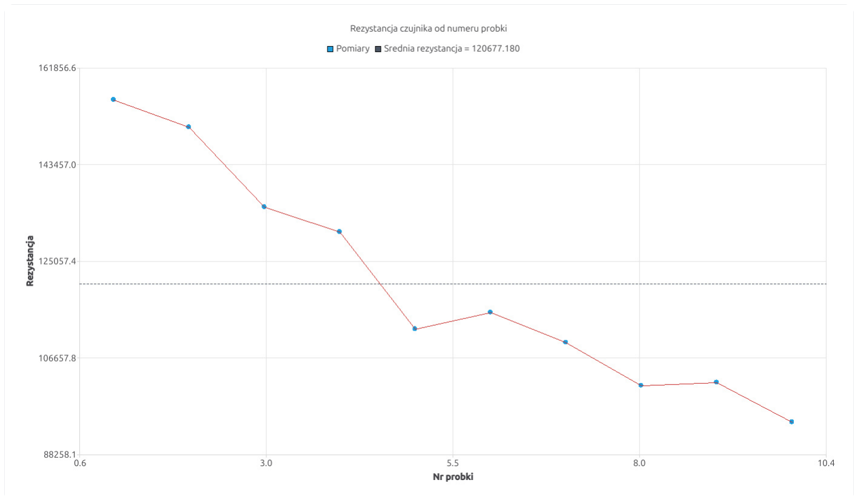
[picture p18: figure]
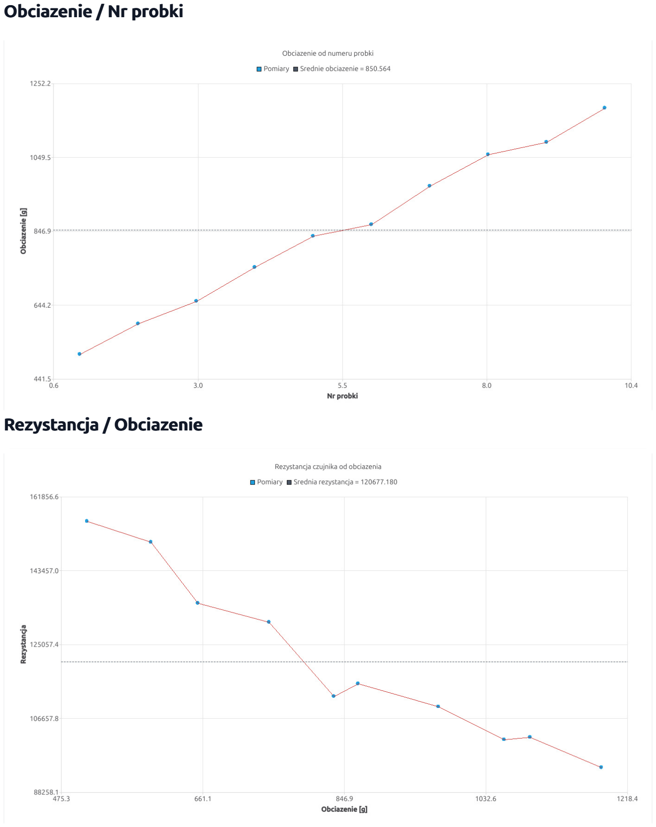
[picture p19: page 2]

Obciazenie / Nr probki

Rezystancja / Obciazenie

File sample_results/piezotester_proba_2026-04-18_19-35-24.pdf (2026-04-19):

# Raport proby PiezoTester V2.0

Wygenerowano: 2026-04-18 19:45:20

Data rozpoczecia
2026-04-18 19:35:24

Data zakonczenia
2026-04-18 19:44:51
Czas trwania
09:27

Liczba probek
30
Typ testu
Narastajacy

Obciazenie start
500.0 g
Obciazenie koniec
1194.4 g

## Komentarz

30 narastający do artykułu

## Wartosci statystyczne

Parametr | Srednia | Min | Max | Odch. std.
Obciazenie [g] | 856.508 | 510.825 | 1212.532 | 211.958
Rezystancja | 122227.800 | 97343.578 | 154401.281 | 17016.548
Rezystancja / Nr probki

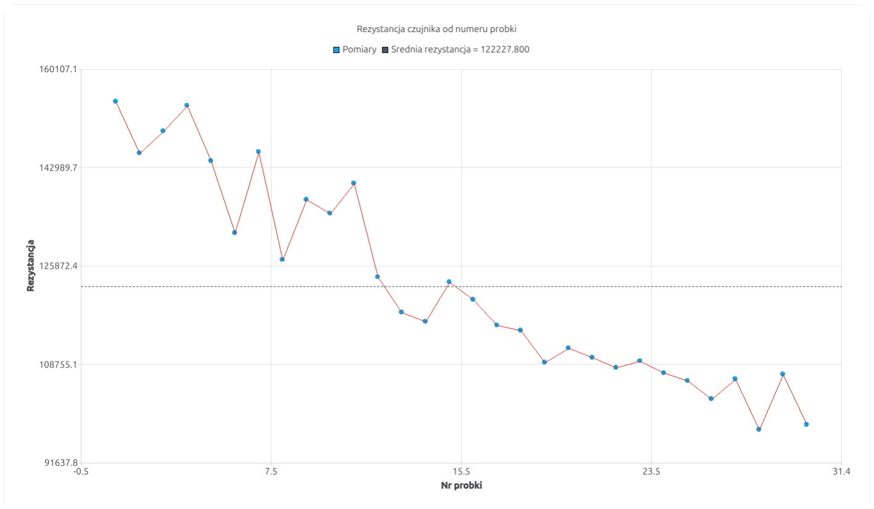
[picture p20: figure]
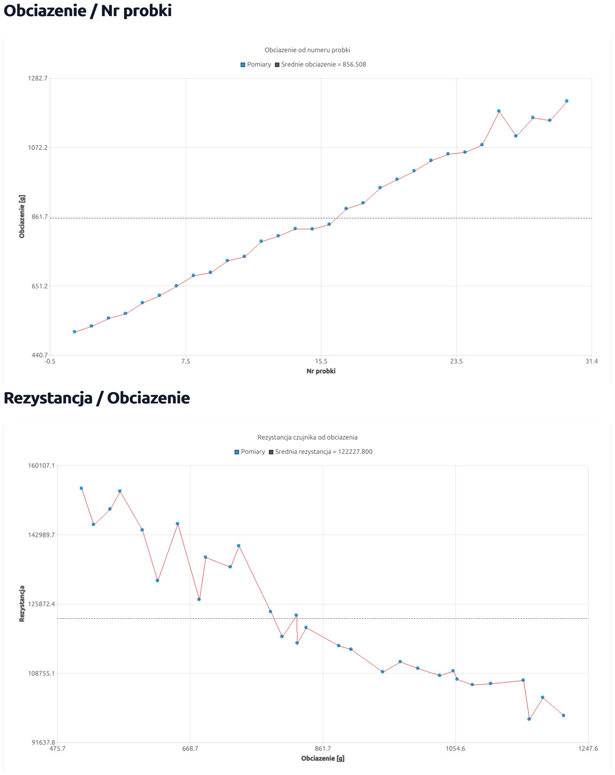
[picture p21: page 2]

Obciazenie / Nr probki

Rezystancja / Obciazenie

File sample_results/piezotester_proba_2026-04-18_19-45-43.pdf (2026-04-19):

# Raport proby PiezoTester V2.0

Wygenerowano: 2026-04-18 19:59:52

Data rozpoczecia
2026-04-18 19:45:43

Data zakonczenia
2026-04-18 19:59:06
Czas trwania
13:22

Liczba probek
50
Typ testu
Standardowy

## Komentarz

50 artykuł

## Wartosci statystyczne

Parametr | Srednia | Min | Max | Odch. std.
Obciazenie [g] | 1379.099 | 1322.734 | 1407.017 | 14.019
Rezystancja | 99208.837 | 88962.070 | 117467.469 | 6200.312
Rezystancja / Nr probki

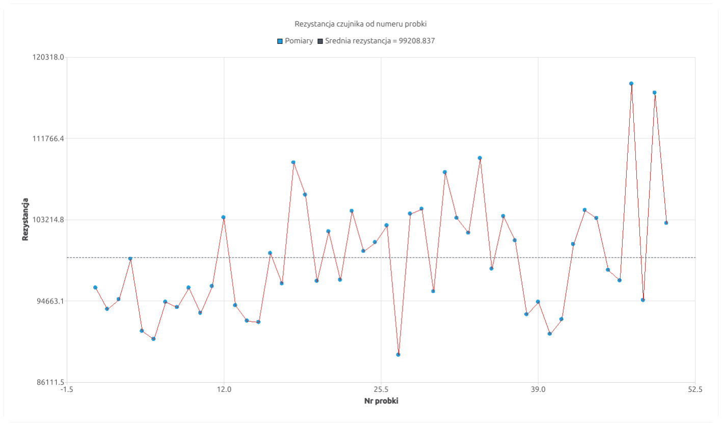
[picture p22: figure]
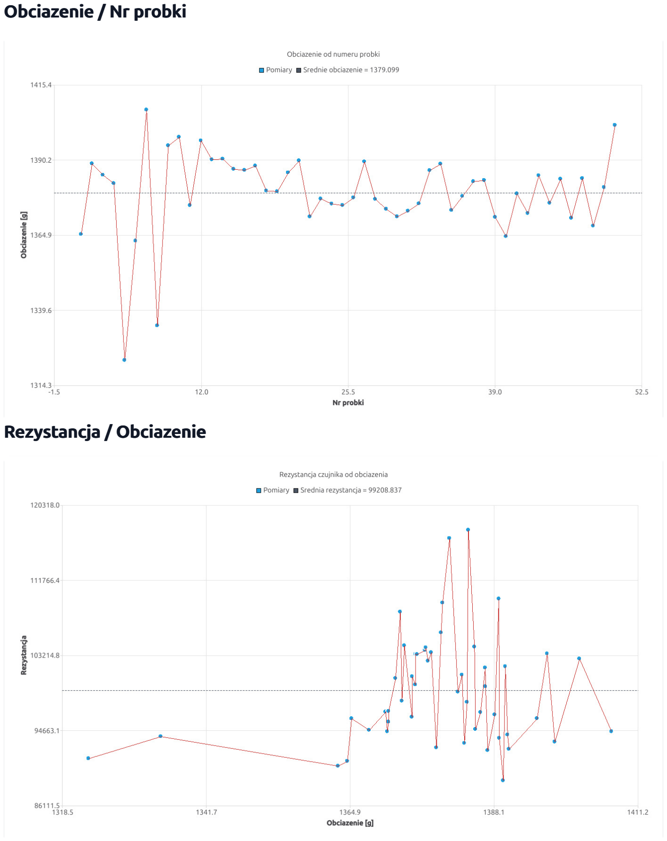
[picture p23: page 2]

Obciazenie / Nr probki

Rezystancja / Obciazenie

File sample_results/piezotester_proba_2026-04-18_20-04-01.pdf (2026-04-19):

# Raport proby PiezoTester V2.0

Wygenerowano: 2026-04-18 20:26:44

Data rozpoczecia
2026-04-18 20:04:01

Data zakonczenia
2026-04-18 20:23:42
Czas trwania
19:40

Liczba probek
49
Typ testu
Narastajacy

Obciazenie start
500.0 g
Obciazenie koniec
1100.0 g

## Komentarz

50 narastający

## Wartosci statystyczne

Parametr | Srednia | Min | Max | Odch. std.
Obciazenie [g] | 812.421 | 528.284 | 1109.267 | 182.098
Rezystancja | 145770.947 | 101147.180 | 202470.750 | 23012.314
Rezystancja / Nr probki


Obciazenie / Nr probki

Rezystancja / Obciazenie

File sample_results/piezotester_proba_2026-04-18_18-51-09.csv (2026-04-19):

Raport proby PiezoTester V2.0
Data rozpoczecia | 2026-04-18 18:51:09
Data zakonczenia | 2026-04-18 19:11:28
Czas trwania | 20:18
Liczba probek | 27
Typ testu | ramp
Obciazenie wstepne [g] | 600.000
Obciazenie koncowe [g] | 1000.000
Statystyki
Parametr | Srednia | Min | Max | Odch. std.
Obciazenie [g] | 993.138 | 890.557 | 1062.518 | 46.910
Rezystancja | 114963.262 | 106311.945 | 127876.797 | 5360.629
date | time | idx | mode | phase | cycle | point | target_g | pwm_duty | pwm_pct | mass_g | resistance | load_v | zero_v | relative_v | sensor_v
2026-04-18 | 18:51:38 | 1 | ramp | none | 0 | 0 | 600.000000 | 7868 | 96.057000 | 923.145000 | 115355.117000 | 0.063307084 | 0.070973717 | 0.134280801 | 1.768831611
2026-04-18 | 18:52:06 | 2 | ramp | none | 0 | 0 | 613.793000 | 7871 | 96.093000 | 929.195000 | 114712.305000 | 0.063721962 | 0.071002863 | 0.134724826 | 1.764244437
2026-04-18 | 18:52:35 | 3 | ramp | none | 0 | 0 | 627.586000 | 7874 | 96.130000 | 923.776000 | 118978.391000 | 0.063350379 | 0.070978239 | 0.134328619 | 1.794183373
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

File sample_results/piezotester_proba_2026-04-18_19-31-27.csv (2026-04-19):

Raport proby PiezoTester V2.0
Data rozpoczecia | 2026-04-18 19:31:27
Data zakonczenia | 2026-04-18 19:34:37
Czas trwania | 03:10
Liczba probek | 10
Typ testu | ramp
Obciazenie wstepne [g] | 500.000
Obciazenie koncowe [g] | 1180.400
Statystyki
Parametr | Srednia | Min | Max | Odch. std.
Obciazenie [g] | 850.564 | 509.100 | 1184.605 | 214.149
Rezystancja | 120677.180 | 94391.328 | 155723.438 | 20185.916
date | time | idx | mode | phase | cycle | point | target_g | pwm_duty | pwm_pct | mass_g | resistance | load_v | zero_v | relative_v | sensor_v
2026-04-18 | 19:31:44 | 1 | ramp | none | 0 | 0 | 500.000000 | 7652 | 93.420000 | 509.100000 | 155723.438000 | 0.034912892 | 0.070999108 | 0.105912000 | 2.010677099
2026-04-18 | 19:32:00 | 2 | ramp | none | 0 | 0 | 575.600000 | 7706 | 94.079000 | 592.981000 | 150528.031000 | 0.040665232 | 0.070993505 | 0.111658737 | 1.983923912
2026-04-18 | 19:32:22 | 3 | ramp | none | 0 | 0 | 651.200000 | 7753 | 94.653000 | 654.583000 | 135330.047000 | 0.044889756 | 0.071014121 | 0.115903877 | 1.898877501
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

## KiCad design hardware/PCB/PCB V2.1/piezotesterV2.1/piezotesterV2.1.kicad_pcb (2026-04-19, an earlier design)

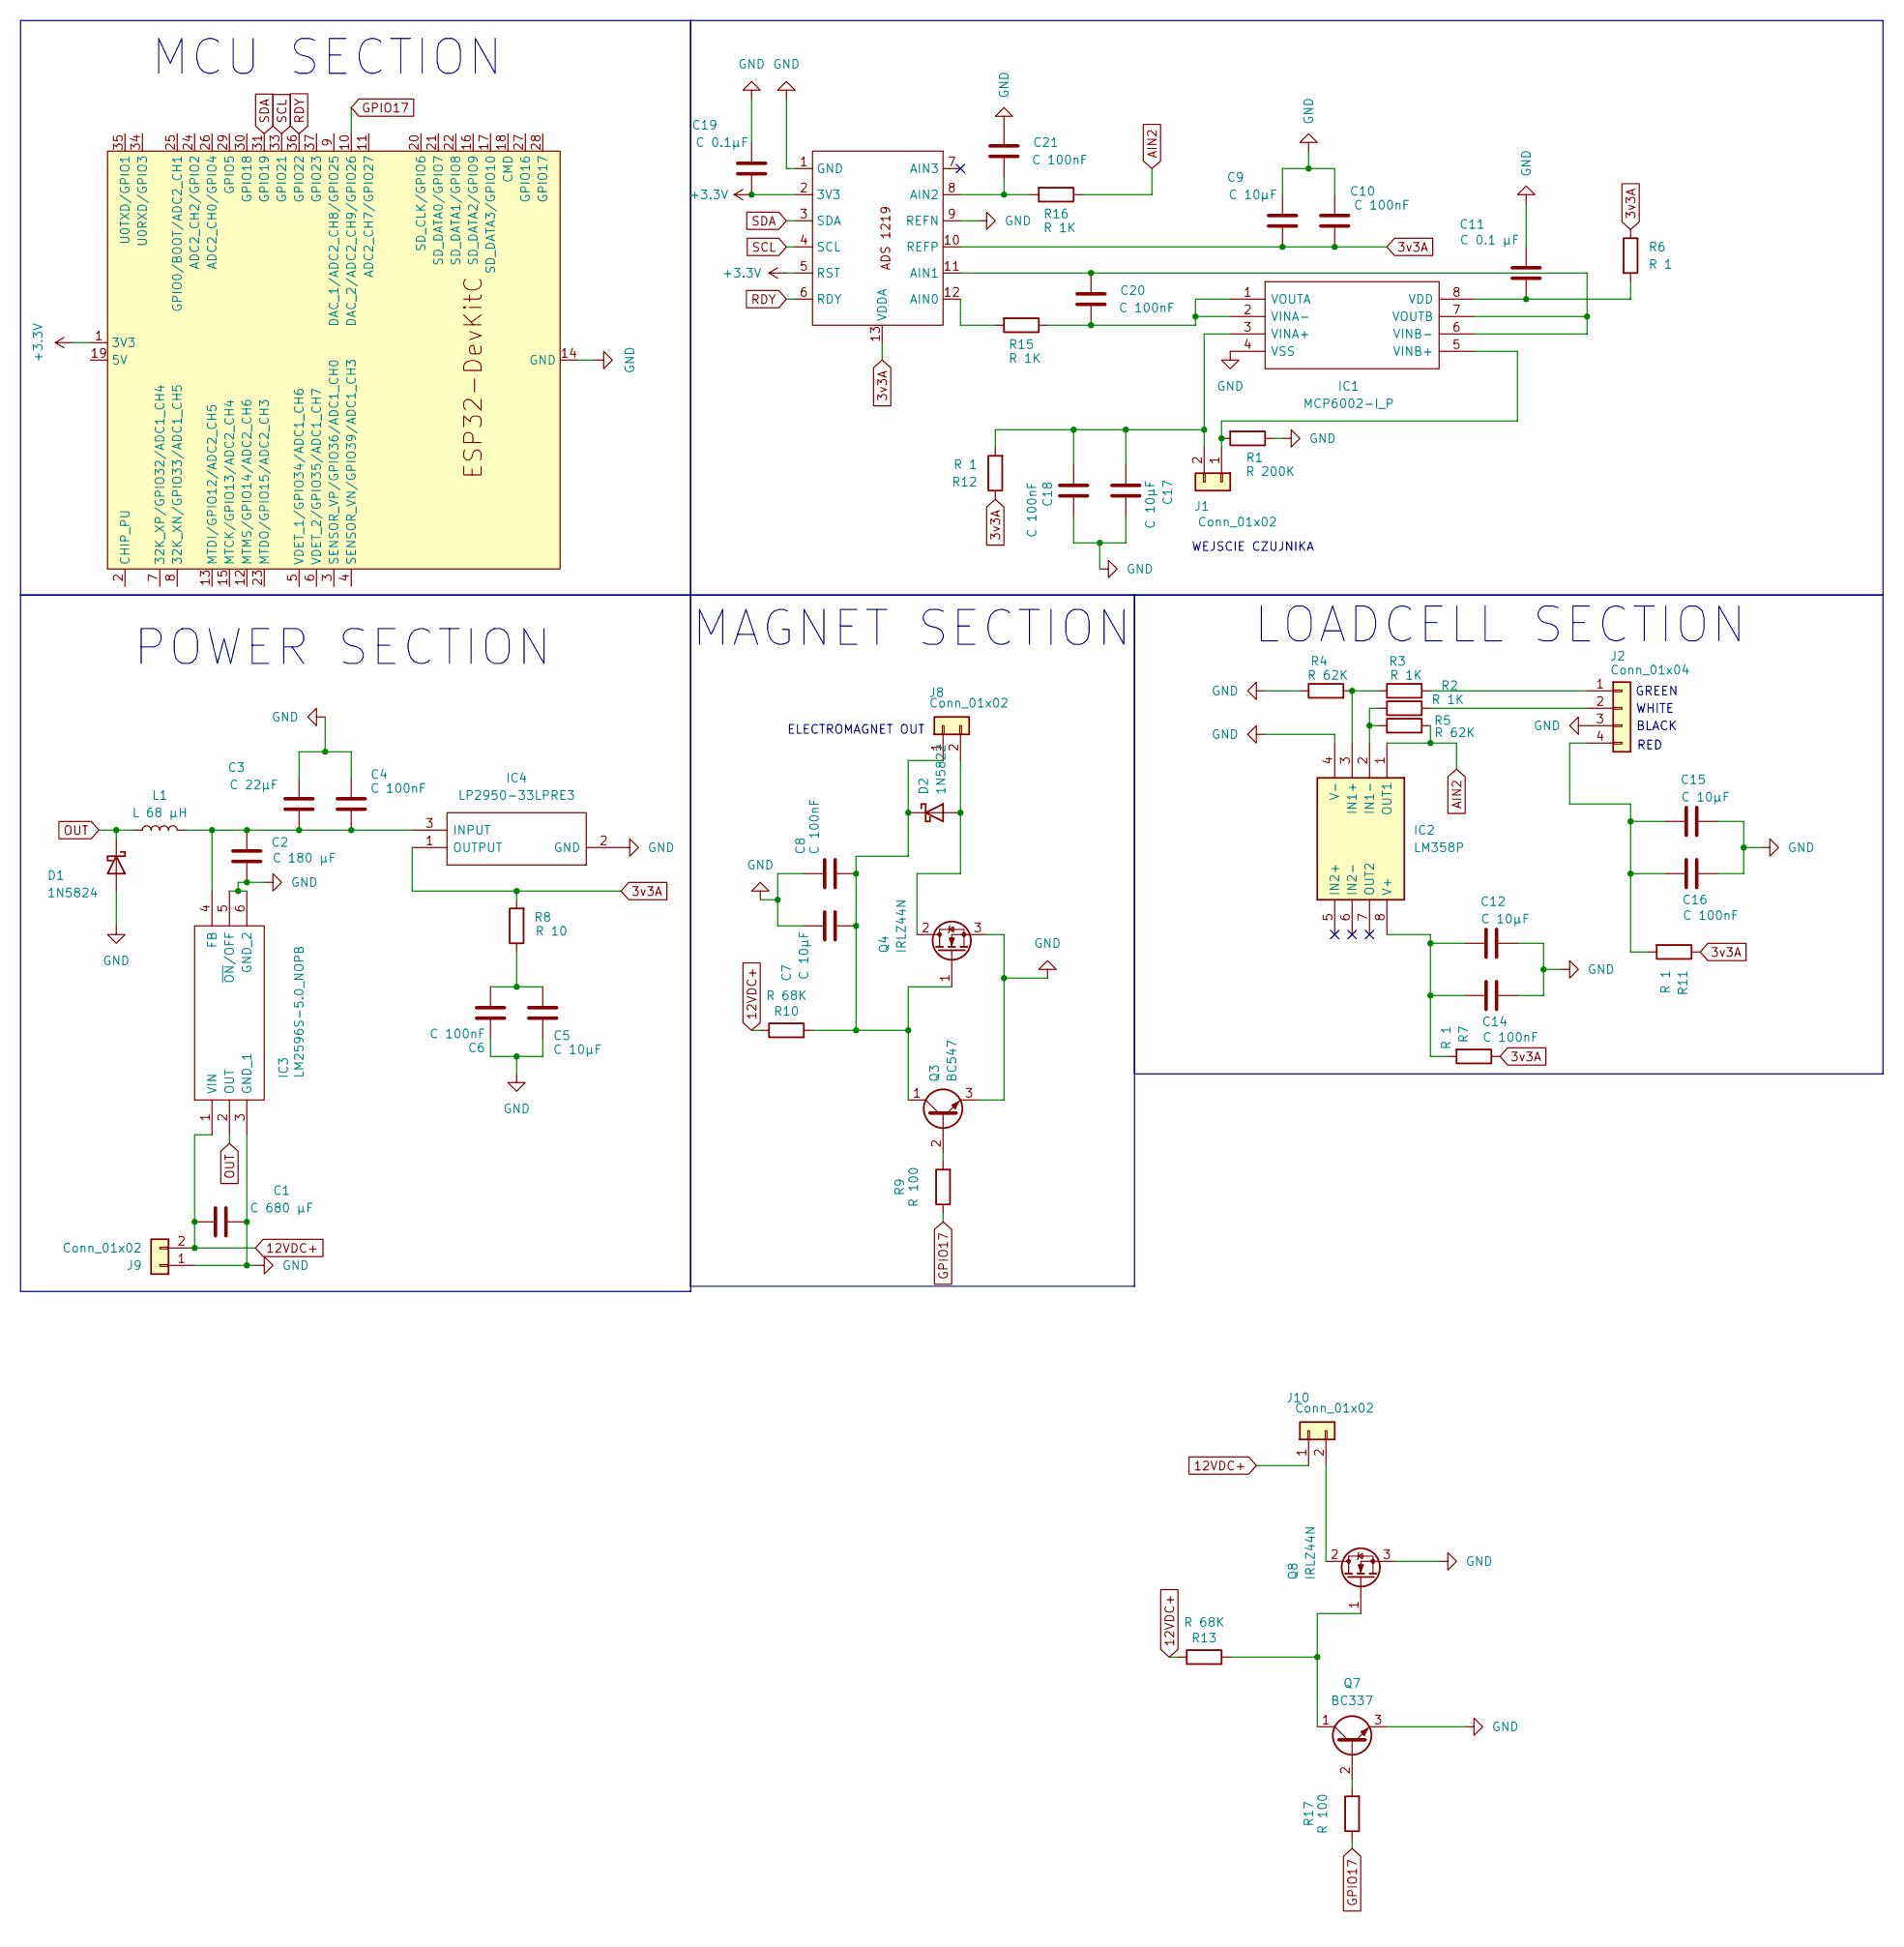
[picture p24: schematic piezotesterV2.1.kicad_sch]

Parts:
ADS2: ADS1219
C1: C 680 μF; CP_Radial_D10.0mm_P5.00mm
C2: C 180 μF; CP_Radial_D8.0mm_P3.50mm
C3: C 22μF; C_1206_3216Metric
C4, C6, C8, C10, C14, C16, C18, C20, C21: C 100nF; C_1206_3216Metric
C5, C7, C9, C12, C15, C17: C 10μF; C_1206_3216Metric
C11: C 0.1 μF; C_1206_3216Metric
C19: C 0.1μF; C_1206_3216Metric
D1: 1N5824; D_DO-201AD_P15.24mm_Horizontal
D2: 1N5822; D_DO-201AD_P15.24mm_Horizontal
IC1: MCP6002-I_P; DIP781W56P254L950H533Q8N; Mouser Part Number 579-MCP6002-I/P
IC2: LM358P; DIP781W56P254L950H533Q8N; Mouser Part Number 595-LM358P
IC3: LM2596S-5.0_NOPB; KTT0005B; Mouser Part Number 926-LM2596S-5.0/NOPB
IC4: LP2950-33LPRE3; TL431CLPM; Mouser Part Number 595-LP2950-33LPRE3
J1, J8, J9, J10: Conn_01x02; PinHeader_1x02_P2.54mm_Horizontal
J2: Conn_01x04; PinHeader_1x04_P2.54mm_Horizontal
L1: L 68 μH; L_12x12mm_H6mm
Q3: BC547; TO-92_Inline
Q4, Q8: IRLZ44N; TO-220-3_Vertical
Q7: BC337; TO-92_Inline
R1: R 200K; R_1206_3216Metric
R2, R3, R15, R16: R 1K; R_1206_3216Metric
R4, R5: R 62K; R_1206_3216Metric
R6, R7, R11, R12: R 1; R_1206_3216Metric
R8: R 10; R_1206_3216Metric
R9, R17: R 100; R_1206_3216Metric
R10, R13: R 68K; R_1206_3216Metric
U1: ESP32-DevKitC

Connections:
3v3A: ADS2.10 (REFP), ADS2.13 (VDDA), C9.1, C10.1, IC4.1 (OUTPUT), R6.1, R7.1, R8.2, R11.1, R12.1
12VDC+: C1.1, IC3.1 (VIN), J9.2, J10.1, R10.1, R13.1
+3.3V: ADS2.2 (3V3), ADS2.5 (RST), C19.1, U1.1 (3V3)
AIN2: IC2.1 (OUT1), R5.2, R16.1
GND: ADS2.1 (GND), ADS2.9 (REFN), C1.2, C2.1, C3.2, C4.2, C5.2, C6.2, C7.2, C8.2, C9.2, C10.2, C11.2, C12.2, C14.2, C15.2, C16.2, C17.2, C18.2, C19.2, C21.2, D1.2 (A), IC1.4 (VSS), IC2.4 (V-), IC3.3 (GND_1), IC3.5 (~ON/OFF), IC3.6 (GND_2), IC4.2 (GND), J2.3, J9.1, Q3.3 (E), Q4.3 (S), Q7.3 (E), Q8.3 (S), R1.1, R4.1, U1.14 (GND), U1.32 (GND), U1.38 (GND)
GPIO17: R9.1, R17.1, U1.10 (DAC_2/ADC2_CH9/GPIO26)
unnamed: ADS2.12 (AIN0), R15.2
unnamed: ADS2.11 (AIN1), C20.2, IC1.6 (VINB-), IC1.7 (VOUTB)
unnamed: ADS2.8 (AIN2), C21.1, R16.2
unnamed: C5.1, C6.1, R8.1
unnamed: D2.2 (A), J8.2, Q4.2 (D)
unnamed: C7.1, C8.1, D2.1 (K), J8.1, Q3.1 (C), Q4.1 (G), R10.2
unnamed: C11.1, IC1.8 (VDD), R6.2
unnamed: C17.1, C18.1, IC1.3 (VINA+), J1.2, R12.2
unnamed: C20.1, IC1.1 (VOUTA), IC1.2 (VINA-), R15.1
unnamed: IC1.5 (VINB+), J1.1, R1.2
unnamed: IC2.3 (IN1+), R3.1, R4.2
unnamed: IC2.2 (IN1-), R2.1, R5.1
unnamed: C12.1, C14.1, IC2.8 (V+), R7.2
unnamed: C2.2, C3.1, C4.1, IC3.4 (FB), IC4.3 (INPUT), L1.2
unnamed: J2.1, R3.2
unnamed: J2.2, R2.2
unnamed: C15.1, C16.1, J2.4, R11.2
unnamed: J10.2, Q8.2 (D)
unnamed: Q3.2 (B), R9.2
unnamed: Q7.1 (C), Q8.1 (G), R13.2
unnamed: Q7.2 (B), R17.2
OUT: D1.1 (K), IC3.2 (OUT), L1.1
RDY: ADS2.6 (RDY), U1.36 (GPIO22)
SCL: ADS2.4 (SCL), U1.33 (GPIO21)
SDA: ADS2.3 (SDA), U1.31 (GPIO19)

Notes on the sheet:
ELECTROMAGNET OUT
WHITE
MCU SECTION
BLACK
POWER SECTION
RED
WEJSCIE CZUJNIKA
MAGNET SECTION
GREEN
LOADCELL SECTION

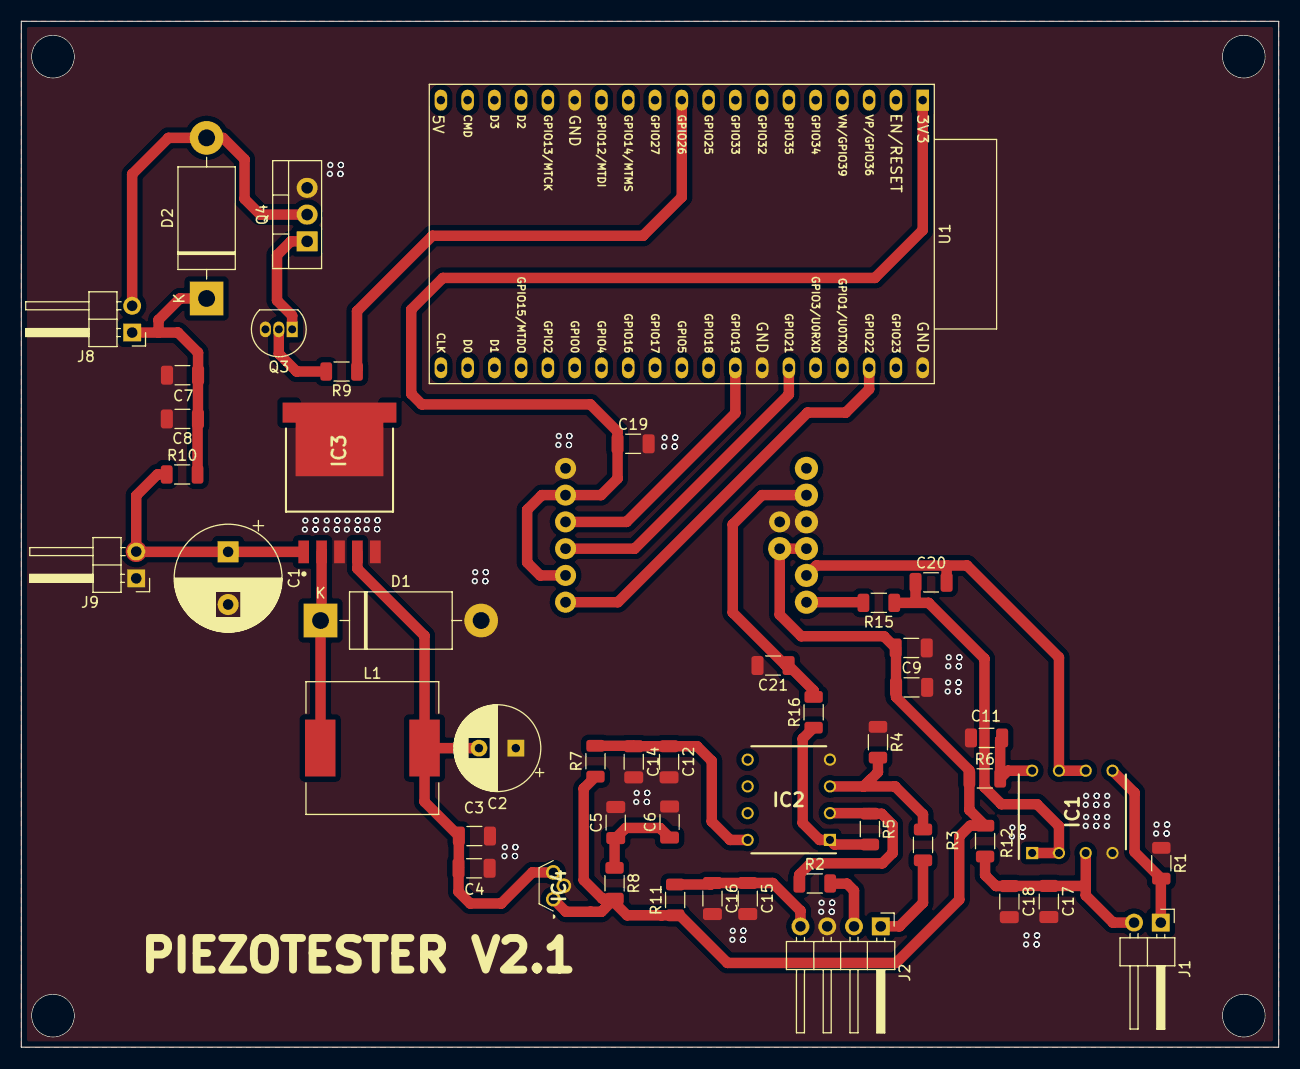
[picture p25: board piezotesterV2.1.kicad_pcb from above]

Board: 2 copper layers, 119.3 x 97.3 mm, 49 parts (0 on the bottom side), 28 nets.

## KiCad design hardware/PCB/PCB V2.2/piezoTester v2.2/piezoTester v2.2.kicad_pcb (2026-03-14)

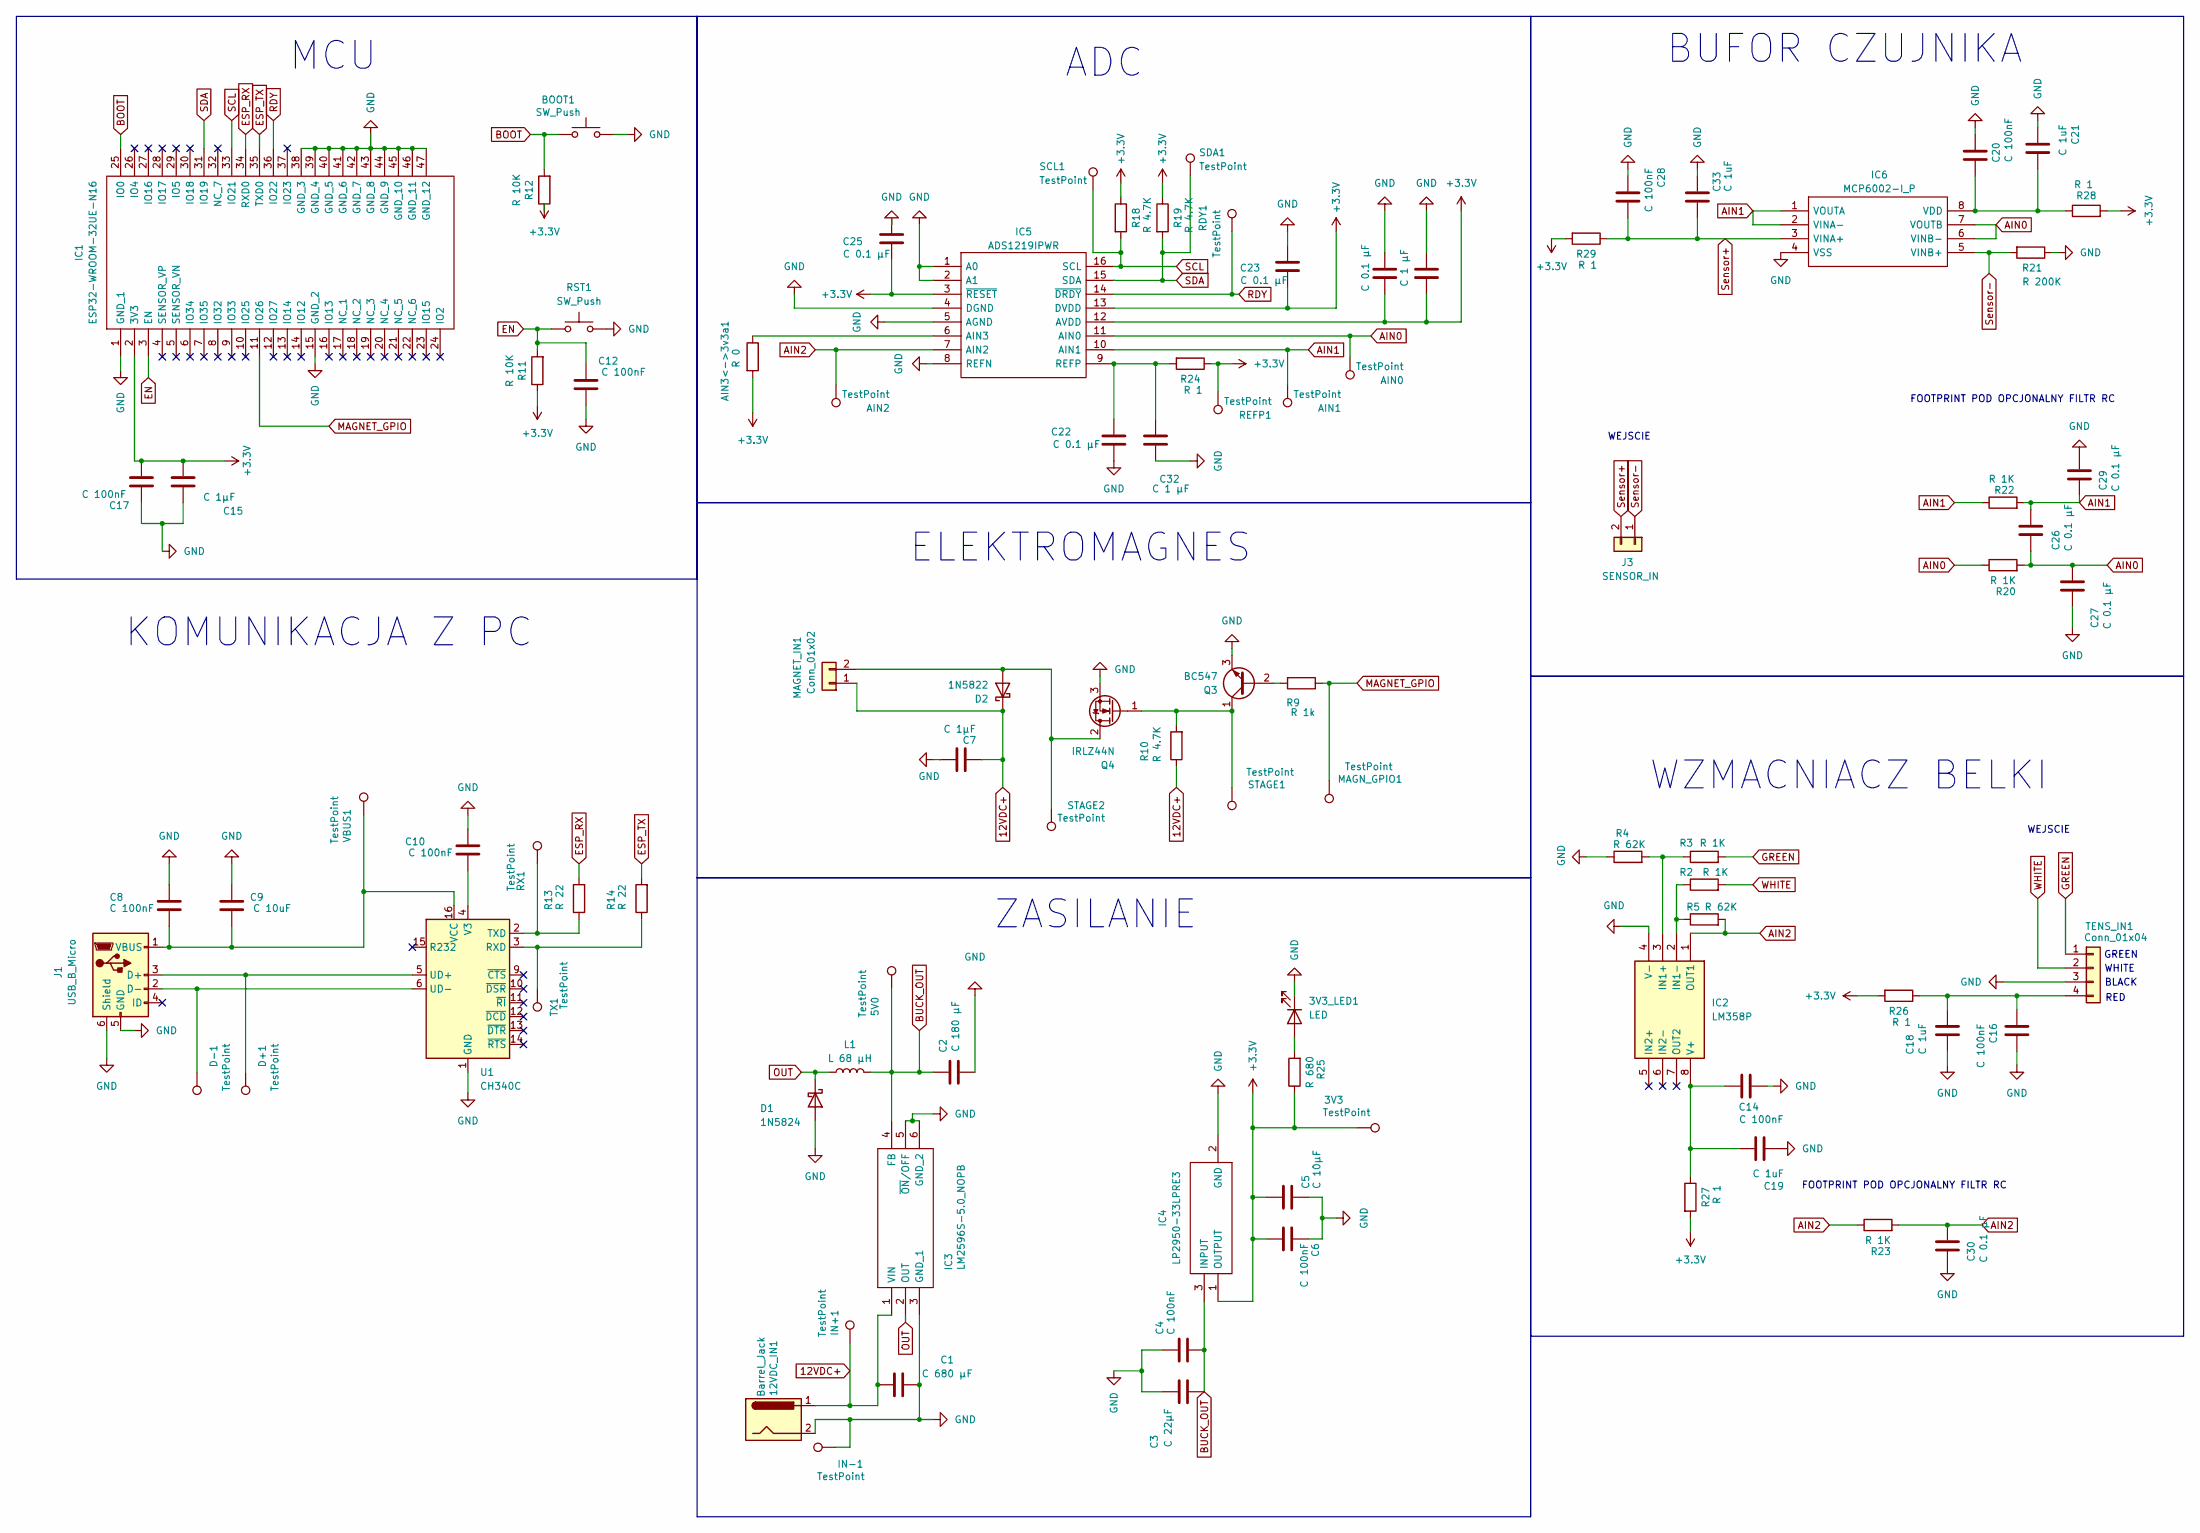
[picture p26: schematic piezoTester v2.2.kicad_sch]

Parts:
3V3, 5V0: TestPoint; TestPoint_Pad_D1.0mm
3V3_LED1: LED; LED_1206_3216Metric_Pad1.42x1.75mm_HandSolder
12VDC_IN1: Barrel_Jack; BarrelJack_Wuerth_694108106102_2.5x5.5mm
AIN0, AIN1, AIN2: TestPoint; TestPoint_Pad_D1.0mm
AIN3<->3v3a1: R 0; R_0603_1608Metric_Pad0.98x0.95mm_HandSolder
BOOT1: SW_Push; SW_PUSH_6mm
C1: C 680 μF; CP_Radial_D10.0mm_P5.00mm
C2: C 180 μF; CP_Radial_D8.0mm_P3.50mm
C3: C 22μF; C_1206_3216Metric_Pad1.33x1.80mm_HandSolder
C4, C6, C10, C12, C28: C 100nF; C_1206_3216Metric_Pad1.33x1.80mm_HandSolder
C5: C 10μF; C_1206_3216Metric_Pad1.33x1.80mm_HandSolder
C7: C 1μF; C_1206_3216Metric_Pad1.33x1.80mm_HandSolder
C8, C14, C16, C17, C20: C 100nF; C_0603_1608Metric_Pad1.08x0.95mm_HandSolder
C9: C 10uF; C_0603_1608Metric_Pad1.08x0.95mm_HandSolder
C15: C 1μF; C_0603_1608Metric_Pad1.08x0.95mm_HandSolder
C18, C19, C21: C 1uF; C_0603_1608Metric_Pad1.08x0.95mm_HandSolder
C22, C23, C24, C25, C26: C 0.1 μF; C_0603_1608Metric_Pad1.08x0.95mm_HandSolder
C27, C29, C30: C 0.1 μF; C_1206_3216Metric_Pad1.33x1.80mm_HandSolder
C31, C32: C 1 μF; C_0603_1608Metric_Pad1.08x0.95mm_HandSolder
C33: C 1uF; C_1206_3216Metric_Pad1.33x1.80mm_HandSolder
D1: 1N5824; D_DO-201AD_P15.24mm_Horizontal
D2: 1N5822; D_DO-201AD_P15.24mm_Horizontal
D+1: TestPoint; TestPoint_Pad_D1.0mm
D-1: TestPoint; TestPoint_Pad_D1.0mm
IC1: ESP32-WROOM-32UE-N16; ESP32WROOM32UEN16; Manufacturer_Part_Number ESP32-WROOM-32UE-N16
IC2: LM358P; DIP781W56P254L950H533Q8N; Mouser Part Number 595-LM358P
IC3: LM2596S-5.0_NOPB; KTT0005B; Mouser Part Number 926-LM2596S-5.0/NOPB
IC4: LP2950-33LPRE3; TL431CLPM; Mouser Part Number 595-LP2950-33LPRE3
IC5: ADS1219IPWR; ads1219; Mouser Part Number 595-ADS1219IPWR
IC6: MCP6002-I_P; DIP781W56P254L950H533Q8N; Mouser Part Number 579-MCP6002-I/P
IN+1: TestPoint; TestPoint_Pad_D1.0mm
IN-1: TestPoint; TestPoint_Pad_D1.0mm
J1: USB_B_Micro; USB_Micro-B_Wuerth_629105150521
J3: SENSOR_IN; PinHeader_1x02_P2.54mm_Vertical
L1: L 68 μH; L_12x12mm_H6mm
MAGNET_IN1: Conn_01x02; PinHeader_1x02_P2.54mm_Vertical
MAGN_GPIO1: TestPoint; TestPoint_Pad_D1.0mm
Q3: BC547; TO-92_Inline
Q4: IRLZ44N; TO-220-3_Horizontal_TabDown
R2, R3, R20, R22, R23: R 1K; R_1206_3216Metric_Pad1.30x1.75mm_HandSolder
R4, R5: R 62K; R_1206_3216Metric_Pad1.30x1.75mm_HandSolder
R9: R 1k; R_1206_3216Metric_Pad1.30x1.75mm_HandSolder
R10: R 4.7K; R_1206_3216Metric_Pad1.30x1.75mm_HandSolder
R11, R12: R 10K; R_1206_3216Metric_Pad1.30x1.75mm_HandSolder
R13, R14: R 22; R_1206_3216Metric_Pad1.30x1.75mm_HandSolder
R18, R19: R 4.7K; R_0603_1608Metric_Pad0.98x0.95mm_HandSolder
R21: R 200K; R_1206_3216Metric_Pad1.30x1.75mm_HandSolder
R24: R 1; R_0603_1608Metric_Pad0.98x0.95mm_HandSolder
R25: R 680; R_1206_3216Metric_Pad1.30x1.75mm_HandSolder
R26, R27, R28, R29: R 1; R_1206_3216Metric_Pad1.30x1.75mm_HandSolder
RDY1: TestPoint; TestPoint_Pad_D1.0mm
REFP1: TestPoint; TestPoint_Pad_D1.0mm
RST1: SW_Push; SW_PUSH_6mm
RX1: TestPoint; TestPoint_Pad_D1.0mm
SCL1: TestPoint; TestPoint_Pad_D1.0mm
SDA1: TestPoint; TestPoint_Pad_D1.0mm
STAGE1, STAGE2: TestPoint; TestPoint_Pad_D1.0mm
TENS_IN1: Conn_01x04; PinHeader_1x04_P2.54mm_Vertical
TX1: TestPoint; TestPoint_Pad_D1.0mm
U1: CH340C; SOIC-16_3.9x9.9mm_P1.27mm
VBUS1: TestPoint; TestPoint_Pad_D1.0mm

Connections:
12VDC+: 12VDC_IN1.1, C1.1, C7.2, D2.1 (K), IC3.1 (VIN), IN+1.1, MAGNET_IN1.1, R10.1
+3.3V: 3V3.1, AIN3<->3v3a1.2, C5.1, C6.1, C15.1, C17.1, C23.1, C24.1, C25.1, C31.1, IC1.2 (3V3), IC4.1 (OUTPUT), IC5.3 (~RESET), IC5.12 (AVDD), IC5.13 (DVDD), R11.1, R12.1, R18.1, R19.1, R24.1, R25.1, R26.2, R27.2, R28.2, R29.2, REFP1.1; also elsewhere on the board
AIN0: AIN0.1, C26.2, C27.1, IC5.11 (AIN0), IC6.6 (VINB-), IC6.7 (VOUTB), R20.1, R20.2; also elsewhere on the board
AIN1: AIN1.1, C26.1, C29.2, IC5.10 (AIN1), IC6.1 (VOUTA), IC6.2 (VINA-), R22.1, R22.2; also elsewhere on the board
AIN2: AIN2.1, C30.1, IC2.1 (OUT1), IC5.7 (AIN2), R5.2, R23.1, R23.2; also elsewhere on the board
BOOT: BOOT1.1, IC1.25 (IO0), R12.2; also elsewhere on the board
BUCK_OUT: 5V0.1, C2.2, C3.1, C4.1, IC3.4 (FB), IC4.3 (INPUT), L1.2; also elsewhere on the board
EN: C12.2, IC1.3 (EN), R11.2, RST1.1; also elsewhere on the board
ESP_RX: IC1.34 (RXD0), R13.2; also elsewhere on the board
ESP_TX: IC1.35 (TXD0), R14.2; also elsewhere on the board
GND: 3V3_LED1.1 (K), 12VDC_IN1.2, BOOT1.2, C1.2, C2.1, C3.2, C4.2, C5.2, C6.2, C7.1, C8.2, C9.2, C10.2, C12.1, C14.2, C15.2, C16.2, C17.2, C18.2, C19.2, C20.2, C21.2, C22.1, C23.2, C24.2, C25.2, C27.2, C28.2, C29.1, C30.2, C31.2, C32.1, C33.1, D1.2 (A), IC1.1 (GND_1), IC1.15 (GND_2), IC1.38 (GND_3), IC1.39 (GND_4), IC1.40 (GND_5), IC1.41 (GND_6), IC1.42 (GND_7), IC1.43 (GND_8), IC1.44 (GND_9), IC1.45 (GND_10), IC1.46 (GND_11), IC1.47 (GND_12), IC2.4 (V-), IC3.3 (GND_1), IC3.5 (~ON/OFF), IC3.6 (GND_2), IC3.7, IC3.8, IC4.2 (GND), IC5.1 (A0), IC5.2 (A1), IC5.4 (DGND), IC5.5 (AGND), IC5.8 (REFN), IC6.4 (VSS), IN-1.1, J1.5 (GND), J1.6 (Shield), Q3.3 (E), Q4.3 (S), R4.1, R21.1, RST1.2, TENS_IN1.3, U1.1 (GND); also elsewhere on the board
GREEN: R3.2, TENS_IN1.1
MAGNET_GPIO: IC1.11 (IO26), MAGN_GPIO1.1, R9.1; also elsewhere on the board
unnamed: 3V3_LED1.2 (A), R25.2
unnamed: D2.2 (A), MAGNET_IN1.2, Q4.2 (D), STAGE2.1
unnamed 15: IC2.3 (IN1+), R3.1, R4.2; also elsewhere on the board
unnamed 16: IC2.2 (IN1-), R2.1, R5.1; also elsewhere on the board
unnamed 17: C14.1, C19.1, IC2.8 (V+), R27.1; also elsewhere on the board
unnamed 18: AIN3<->3v3a1.1, IC5.6 (AIN3); also elsewhere on the board
unnamed: C22.2, C32.2, IC5.9 (REFP), R24.2
unnamed 20: C20.1, C21.1, IC6.8 (VDD), R28.1; also elsewhere on the board
unnamed: D+1.1, J1.3 (D+), U1.5 (UD+)
unnamed: D-1.1, J1.2 (D-), U1.6 (UD-)
unnamed: C8.1, C9.1, J1.1 (VBUS), U1.16 (VCC), VBUS1.1
unnamed: Q3.2 (B), R9.2
unnamed: Q3.1 (C), Q4.1 (G), R10.2, STAGE1.1
unnamed: C16.1, C18.1, R26.1, TENS_IN1.4
unnamed: R14.1, TX1.1, U1.3 (RXD)
unnamed: R13.1, RX1.1, U1.2 (TXD)
unnamed: C10.1, U1.4 (V3)
OUT: D1.1 (K), IC3.2 (OUT), L1.1
RDY: IC1.36 (IO22), IC5.14 (~DRDY), RDY1.1; also elsewhere on the board
SCL: IC1.33 (IO21), IC5.16 (SCL), R18.2, SCL1.1; also elsewhere on the board
SDA: IC1.31 (IO19), IC5.15 (SDA), R19.2, SDA1.1; also elsewhere on the board
Sensor+: C28.1, C33.2, IC6.3 (VINA+), J3.2, R29.1; also elsewhere on the board
Sensor-: IC6.5 (VINB+), J3.1, R21.2; also elsewhere on the board
WHITE: R2.2, TENS_IN1.2

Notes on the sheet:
WEJSCIE
FOOTPRINT POD OPCJONALNY FILTR RC
WHITE
BLACK
BUFOR CZUJNIKA
KOMUNIKACJA Z PC
ZASILANIE
RED
MCU
ELEKTROMAGNES
GREEN
ADC
WZMACNIACZ BELKI

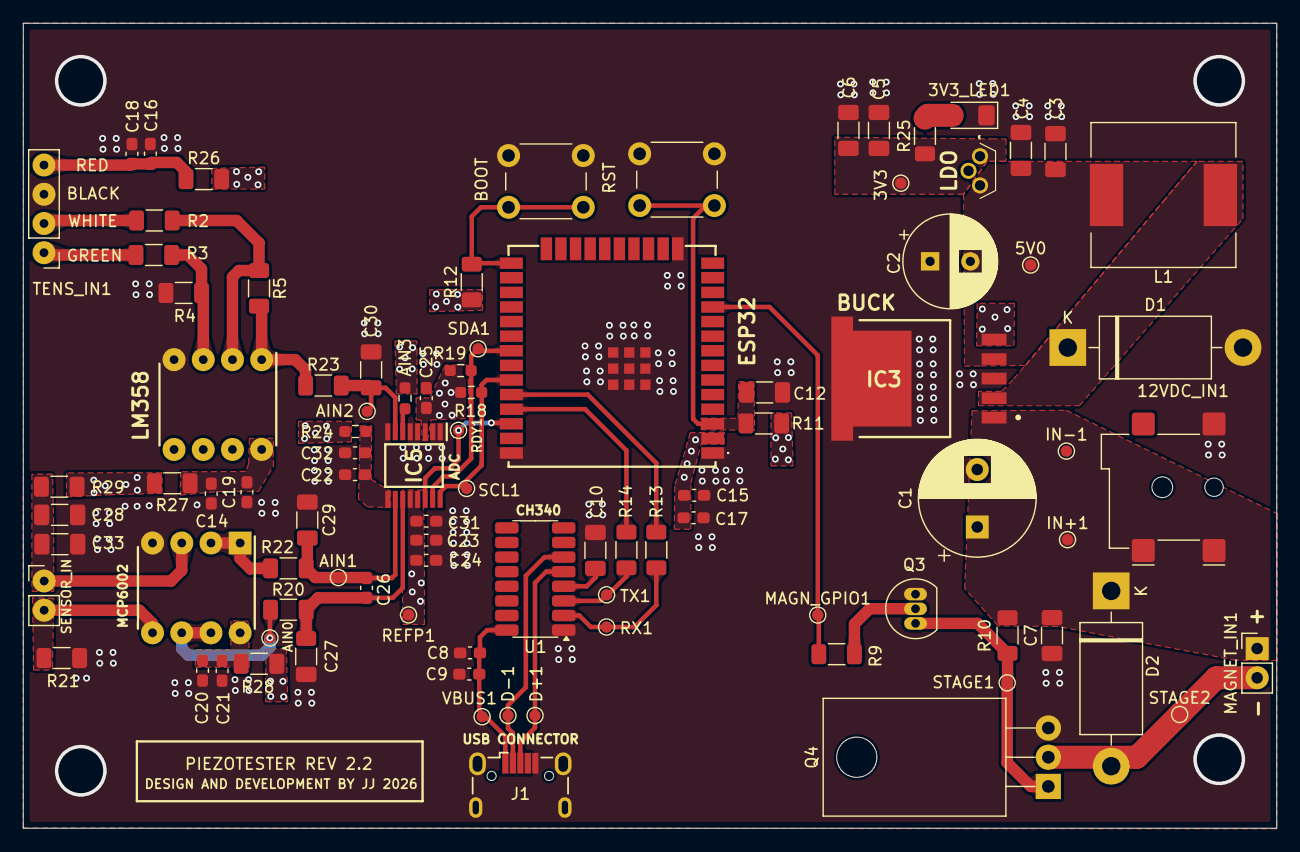
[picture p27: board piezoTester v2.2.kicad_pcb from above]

Board: 4 copper layers, 109.0 x 70.0 mm, 93 parts (0 on the bottom side), 37 nets.

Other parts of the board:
AIN3: R 0; R_0603_1608Metric_Pad0.98x0.95mm_HandSolder
BOOT: SW_Push; SW_PUSH_6mm
ESP32: ESP32-WROOM-32UE-N16; ESP32WROOM32UEN16
LDO: LP2950-33LPRE3; TL431CLPM
LM358: LM358P; DIP781W56P254L950H533Q8N
MCP6002: MCP6002-I_P; DIP781W56P254L950H533Q8N
RST: SW_Push; SW_PUSH_6mm
SENSOR_IN: SENSOR_IN; PinHeader_1x02_P2.54mm_Vertical

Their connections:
+3.3V: AIN3.2, ESP32.2 (3V3), LDO.1 (OUTPUT); also elsewhere on the board
AIN0: MCP6002.6 (VINB-), MCP6002.7 (VOUTB); also elsewhere on the board
AIN1: MCP6002.1 (VOUTA), MCP6002.2 (VINA-); also elsewhere on the board
AIN2: LM358.1 (OUT1); also elsewhere on the board
BOOT: BOOT.1, ESP32.25 (IO0); also elsewhere on the board
BUCK_OUT: LDO.3 (INPUT); also elsewhere on the board
EN: ESP32.3 (EN), RST.1; also elsewhere on the board
ESP_RX: ESP32.34 (RXD0); also elsewhere on the board
ESP_TX: ESP32.35 (TXD0); also elsewhere on the board
GND: BOOT.2, ESP32.1 (GND_1), ESP32.15 (GND_2), ESP32.38 (GND_3), ESP32.39 (GND_4), ESP32.40 (GND_5), ESP32.41 (GND_6), ESP32.42 (GND_7), ESP32.43 (GND_8), ESP32.44 (GND_9), ESP32.45 (GND_10), ESP32.46 (GND_11), ESP32.47 (GND_12), LDO.2 (GND), LM358.4 (V-), MCP6002.4 (VSS), RST.2; also elsewhere on the board
MAGNET_GPIO: ESP32.11 (IO26); also elsewhere on the board
unnamed 15: LM358.3 (IN1+); also elsewhere on the board
unnamed 16: LM358.2 (IN1-); also elsewhere on the board
unnamed 17: LM358.8 (V+); also elsewhere on the board
unnamed 18: AIN3.1; also elsewhere on the board
unnamed 20: MCP6002.8 (VDD); also elsewhere on the board
RDY: ESP32.36 (IO22); also elsewhere on the board
SCL: ESP32.33 (IO21); also elsewhere on the board
SDA: ESP32.31 (IO19); also elsewhere on the board
Sensor+: MCP6002.3 (VINA+), SENSOR_IN.2; also elsewhere on the board
Sensor-: MCP6002.5 (VINB+), SENSOR_IN.1; also elsewhere on the board

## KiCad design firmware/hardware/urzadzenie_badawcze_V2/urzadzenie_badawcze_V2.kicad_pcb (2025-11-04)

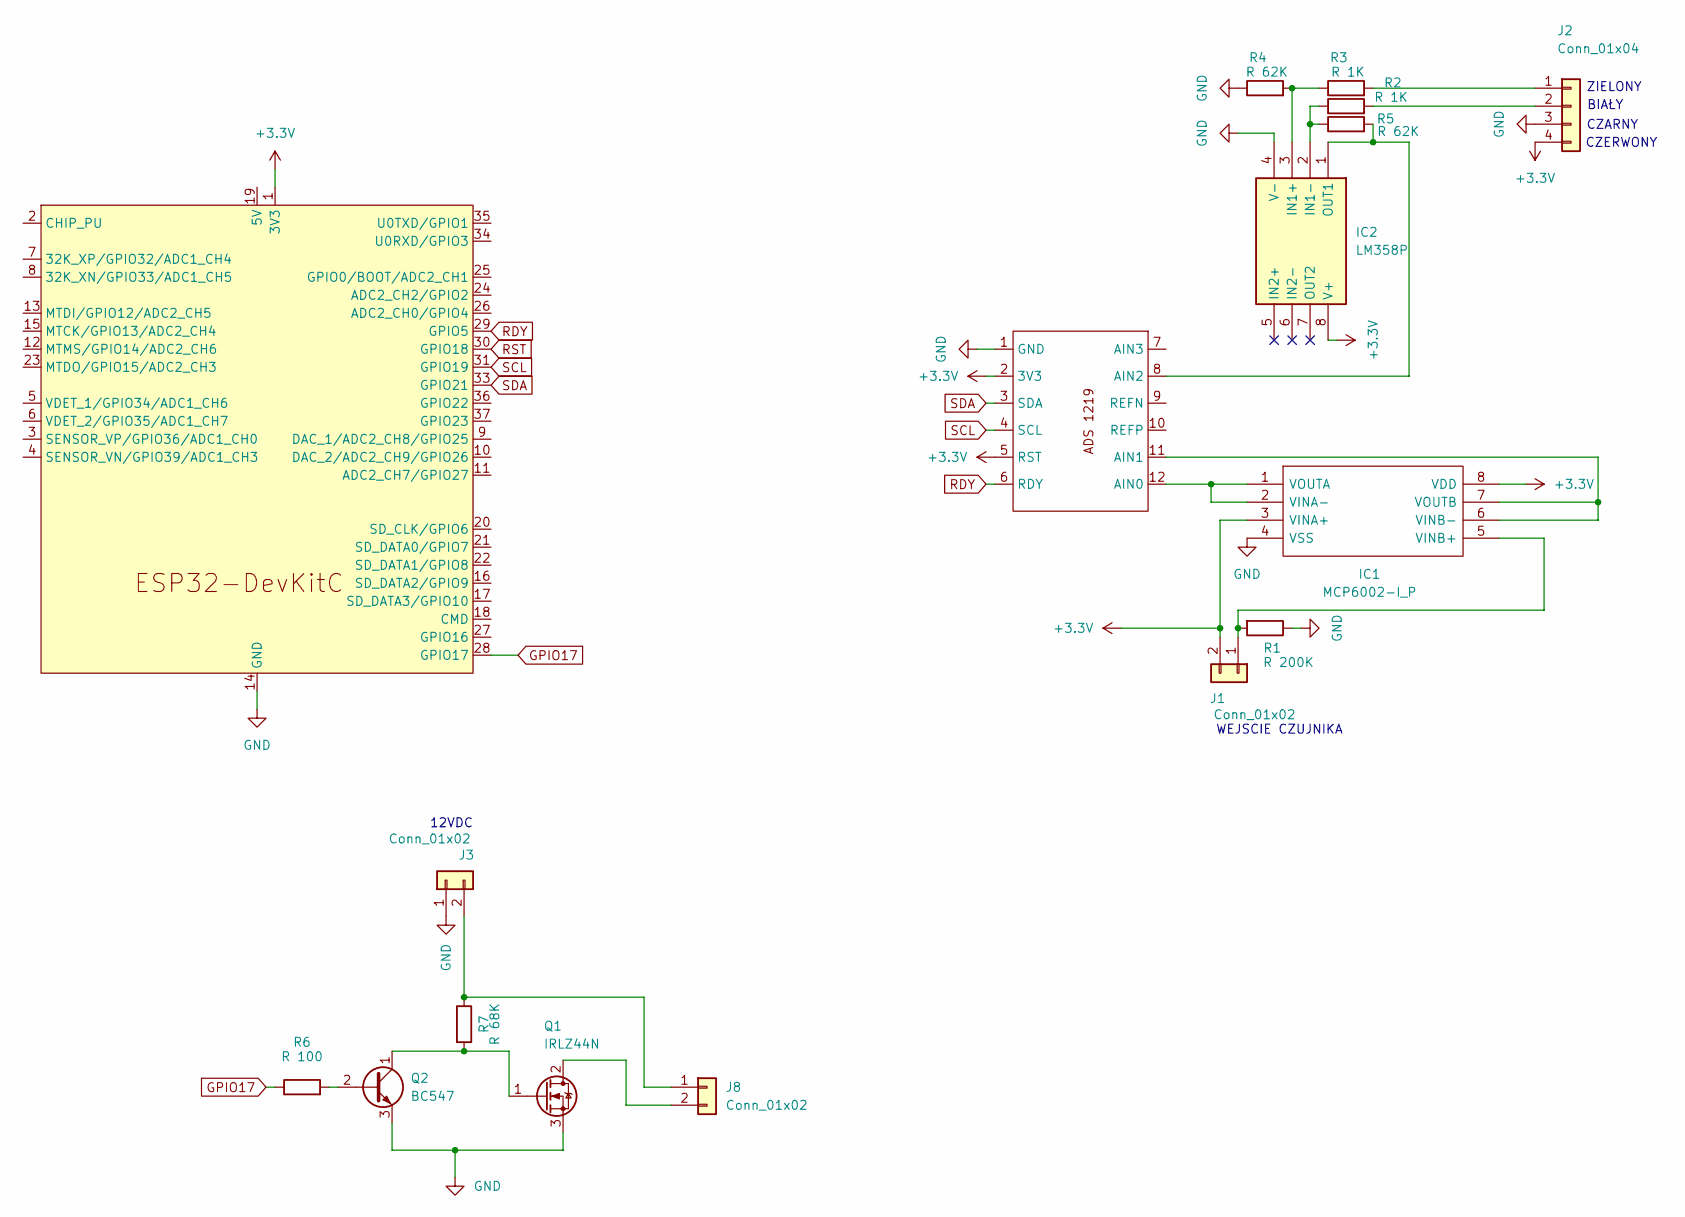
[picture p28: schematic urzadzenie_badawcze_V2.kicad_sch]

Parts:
ADS2: ADS1219
IC1: MCP6002-I_P; DIP781W56P254L950H533Q8N; Mouser Part Number 579-MCP6002-I/P
IC2: LM358P; DIP781W56P254L950H533Q8N; Mouser Part Number 595-LM358P
J1, J3, J8: Conn_01x02; PinHeader_1x02_P2.54mm_Vertical
J2: Conn_01x04; PinHeader_1x04_P2.54mm_Vertical
Q1: IRLZ44N; TO-220-3_Vertical
Q2: BC547; TO-92_Inline
R1: R 200K; R_Axial_DIN0207_L6.3mm_D2.5mm_P7.62mm_Horizontal
R2, R3: R 1K; R_Axial_DIN0207_L6.3mm_D2.5mm_P7.62mm_Horizontal
R4, R5: R 62K; R_Axial_DIN0207_L6.3mm_D2.5mm_P7.62mm_Horizontal
R6: R 100; R_Axial_DIN0207_L6.3mm_D2.5mm_P7.62mm_Horizontal
R7: R 68K; R_Axial_DIN0207_L6.3mm_D2.5mm_P7.62mm_Horizontal
U1: ESP32-DevKitC

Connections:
+3.3V: ADS2.2 (3V3), ADS2.5 (RST), IC1.3 (VINA+), IC1.8 (VDD), IC2.8 (V+), J1.2, J2.4, U1.1 (3V3)
GND: ADS2.1 (GND), IC1.4 (VSS), IC2.4 (V-), J2.3, J3.1, Q1.3 (S), Q2.3 (E), R1.1, R4.1, U1.14 (GND), U1.32 (GND), U1.38 (GND)
GPIO17: R6.1, U1.28 (GPIO17)
unnamed: ADS2.12 (AIN0), IC1.1 (VOUTA), IC1.2 (VINA-)
unnamed: ADS2.11 (AIN1), IC1.6 (VINB-), IC1.7 (VOUTB)
unnamed: ADS2.8 (AIN2), IC2.1 (OUT1), R5.2
unnamed: IC1.5 (VINB+), J1.1, R1.2
unnamed: IC2.3 (IN1+), R3.1, R4.2
unnamed: IC2.2 (IN1-), R2.1, R5.1
unnamed: J2.1, R3.2
unnamed: J2.2, R2.2
unnamed: J3.2, J8.1, R7.1
unnamed: J8.2, Q1.2 (D)
unnamed: Q1.1 (G), Q2.1 (C), R7.2
unnamed: Q2.2 (B), R6.2
RDY: ADS2.6 (RDY), U1.29 (GPIO5)
RST: U1.30 (GPIO18)
SCL: ADS2.4 (SCL), U1.31 (GPIO19)
SDA: ADS2.3 (SDA), U1.33 (GPIO21)

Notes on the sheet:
12VDC
BIAŁY
CZARNY
CZERWONY
WEJSCIE CZUJNIKA
ZIELONY

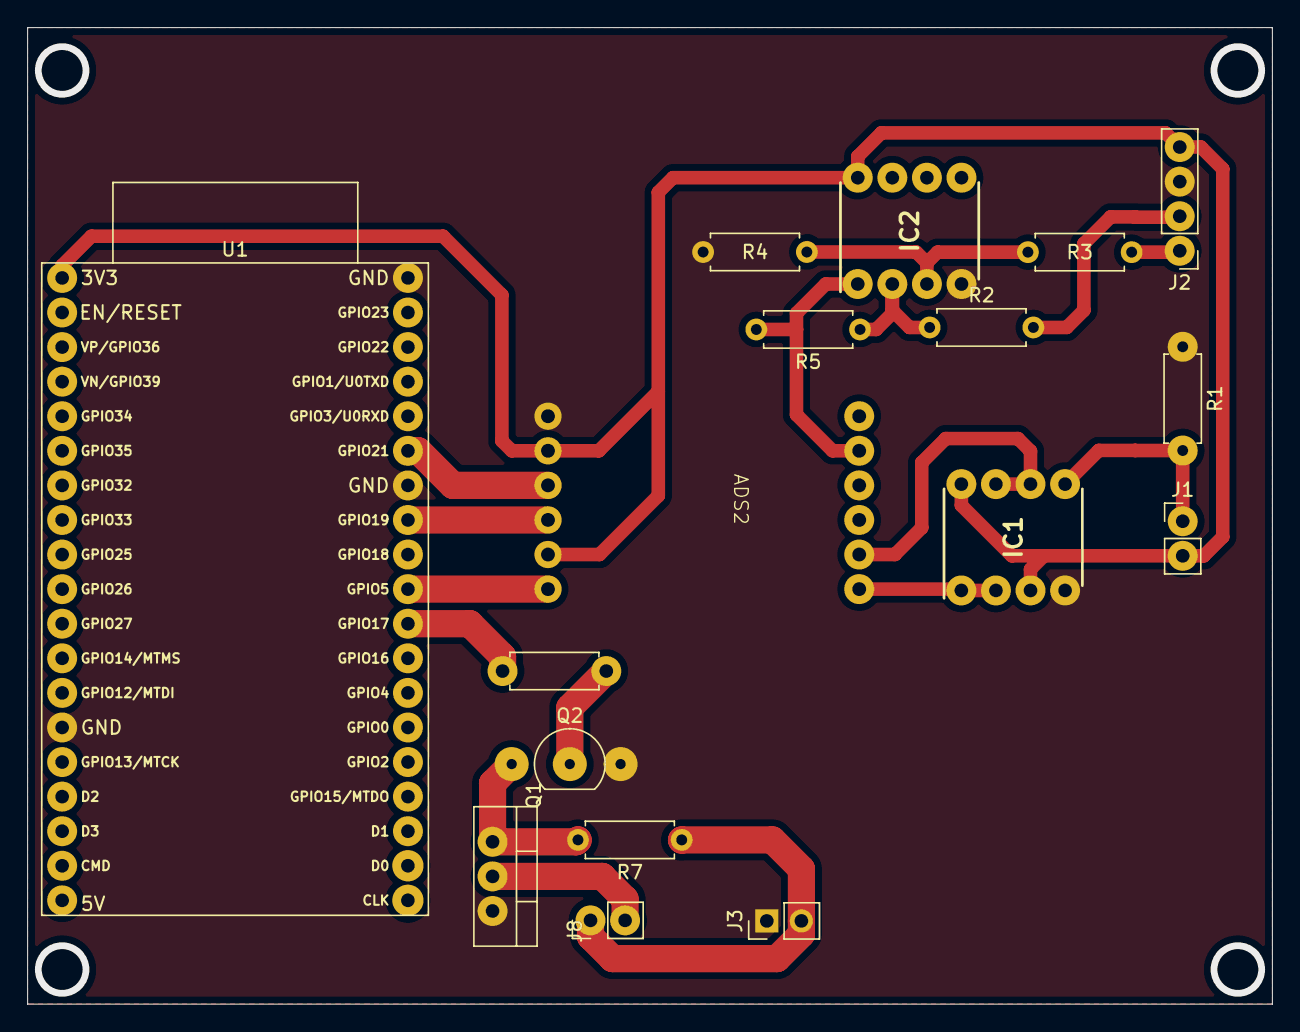
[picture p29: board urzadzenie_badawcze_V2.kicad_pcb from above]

Board: 2 copper layers, 91.4 x 71.7 mm, 17 parts (0 on the bottom side), 18 nets.

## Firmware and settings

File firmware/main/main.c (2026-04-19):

/**
 * @file main.c
 * @brief Main application logic for the PiezoTester V2.0 ESP32 firmware.
 *
 * This module integrates the full measurement pipeline:
 * - load-cell signal acquisition and calibration
 * - sensor-path resistance reconstruction and calibration
 * - electromagnet threshold learning and PWM-to-load model storage
 * - standard, ramp, and hysteresis session execution
 * - UART command handling used by the desktop application
 */

#include <stdbool.h>
#include <stdint.h>
#include <math.h>
#include <stdio.h>
#include <stdlib.h>
#include <stdarg.h>
#include <string.h>

#include "freertos/FreeRTOS.h"
#include "freertos/task.h"
#include "driver/gpio.h"
#include "driver/ledc.h"
#include "esp_timer.h"
#include "nvs.h"
#include "nvs_flash.h"
#include "uart.h"
#include "i2c.h"
#include "ads1219.h"

static const float V_SUPPLY = 3.3f;
static const float VREF_EXT = 3.3f;
static const float R1 = 100000.0f;
static const float RESISTANCE_MEASURED = 198496.0f;
static const float RESISTANCE_OMOMETHER = 197600.0f;
static const float LOAD_CELL_CAPACITY_KG = 5.0f;
static const float LOAD_CELL_SENSITIVITY_MV_V = 2.0f;
static const float LOAD_CELL_EXCITATION_V = 3.3f;
static const float LOAD_CELL_HARDWARE_GAIN = 62.0f;
static const uint8_t LOAD_CALIBRATION_VERSION = 2;
static const uint8_t ELECTROMAGNET_MODEL_VERSION = 2;
static const uint8_t ELECTROMAGNET_PREMODEL_VERSION = 2;
static const uint8_t ELECTROMAGNET_CONTACT_POINTS_VERSION = 1;

#define MOSFET_PIN GPIO_NUM_26
#define MOSFET_ON_LEVEL 0
#define MOSFET_OFF_LEVEL 1

#define ELECTROMAGNET_PWM_TIMER LEDC_TIMER_0
#define ELECTROMAGNET_PWM_MODE LEDC_LOW_SPEED_MODE
#define ELECTROMAGNET_PWM_CHANNEL LEDC_CHANNEL_0
#define ELECTROMAGNET_PWM_FREQ_HZ 5000
#define ELECTROMAGNET_PWM_RESOLUTION LEDC_TIMER_13_BIT
#define ELECTROMAGNET_PWM_MAX_DUTY ((1U << 13) - 1U)
#define ELECTROMAGNET_SETTLE_MS 1300
#define ELECTROMAGNET_COOLDOWN_MS 300
#define ELECTROMAGNET_TARGET_ATTEMPTS 3
#define ELECTROMAGNET_POINT_TOLERANCE_G 60.0f
#define ELECTROMAGNET_MIN_LEARNED_MASS_G 10.0f
#define ELECTROMAGNET_MODEL_MAX_POINTS 16
#define ELECTROMAGNET_PULSE_DEFAULT_MS 1500
#define ELECTROMAGNET_CONTACT_POINT_MAX_COUNT 32
#define ELECTROMAGNET_CONTACT_POINT_DEFAULT_COUNT 10
#define ELECTROMAGNET_CONTACT_POINT_DEFAULT_START_PCT 95.5f
#define ELECTROMAGNET_CONTACT_POINT_DEFAULT_END_PCT 100.0f

#define ZERO_AVG_SAMPLES 8
#define AVG_SAMPLES 8
#define FAST_ZERO_AVG_SAMPLES 4
#define FAST_AVG_SAMPLES 4
#define CAL_STAGE_MEASUREMENTS 4
#define HYSTERESIS_BURST_SAMPLES 12
#define HYSTERESIS_TRACE_POINTS 24
#define HYSTERESIS_TRACE_INTERVAL_MS 2
#define INTER_SAMPLE_DELAY_MS 10000

/**
 * @brief Persistent load-cell calibration model stored in NVS.
 */
typedef struct {
    bool valid;
    float a;
    float b;
    float cal_mass_1;
    float cal_mass_2;
    float cal_diff_1;
    float cal_diff_2;
} calibration_data_t;

/**
 * @brief Persistent sensor-path calibration data stored in NVS.
 */
typedef struct {
    bool valid;
    float factor;
    float reference_resistance;
    float raw_resistance;
    float measured_voltage;
} sensor_calibration_t;

/**
 * @brief Fully processed test result returned to the desktop application.
 */
typedef struct {
    float load_voltage;
    float load_zero;
    float load_relative;
    float mass_kg;
    float mass_g;
    float target_mass_g;
    float sensor_voltage;
    float sensor_resistance;
    uint32_t pwm_duty;
    float pwm_percent;
    uint32_t session_index;
    uint8_t mode;
    uint8_t phase;
    uint16_t cycle_index;
    uint16_t phase_point;
} test_result_t;

/**
 * @brief Measurement session modes supported by the firmware.
 */
typedef enum {
    TEST_MODE_STANDARD = 0,
    TEST_MODE_RAMP = 1,
    TEST_MODE_HYSTERESIS = 2,
} test_mode_t;

/**
 * @brief Phase label used mainly by hysteresis traces.
 */
typedef enum {
    TEST_PHASE_NONE = 0,
    TEST_PHASE_LOADING = 1,
    TEST_PHASE_UNLOADING = 2,
} test_phase_t;

/**
 * @brief State machine for the one-point load-cell calibration workflow.
 */
typedef enum {
    CAL_STATE_IDLE = 0,
    CAL_STATE_WAIT_ZERO,
    CAL_STATE_WAIT_POINT,
    CAL_STATE_READY_TO_SAVE,
} calibration_state_t;

/**
 * @brief Empirical PWM-to-load model used by the ramp controller.
 */
typedef struct {
    uint8_t point_count;
    float mass_g[ELECTROMAGNET_MODEL_MAX_POINTS];
    uint16_t pwm_duty[ELECTROMAGNET_MODEL_MAX_POINTS];
} electromagnet_model_t;

/**
 * @brief Coarse electromagnet premodel based on movement and contact thresholds.
 */
typedef struct {
    bool valid;
    uint16_t move_threshold_duty;
    uint16_t contact_threshold_duty;
    float full_scale_mass_g;
} electromagnet_premodel_t;

/**
 * @brief Contact calibration table used to classify PWM points.
 */
typedef struct {
    uint8_t point_count;
    float start_pct;
    float end_pct;
    uint8_t state[ELECTROMAGNET_CONTACT_POINT_MAX_COUNT];
} electromagnet_contact_points_t;

/**
 * @brief Runtime state for the currently active measurement session.
 */
typedef struct {
    bool active;
    test_mode_t mode;
    uint16_t sample_count;
    uint16_t hysteresis_points;
    uint16_t current_index;
    float start_mass_g;
    float end_mass_g;
    uint32_t start_pwm_duty;
    uint32_t end_pwm_duty;
    uint16_t hysteresis_trace_count;
    uint16_t hysteresis_trace_index;
    uint16_t hysteresis_trace_cycle;
    bool hysteresis_trace_ready;
    test_result_t hysteresis_trace[(HYSTERESIS_TRACE_POINTS * 2U)];
} test_session_t;

static calibration_data_t g_calibration = {
    .valid = false,
    .a = 1.0f,
    .b = 1.0f,
};

static sensor_calibration_t g_sensor_calibration = {
    .valid = false,
    .factor = 1.0f,
    .reference_resistance = 0.0f,
    .raw_resistance = 0.0f,
    .measured_voltage = 0.0f,
};

static float g_calibration_zero = 0.0f;
static float g_preview_zero = 0.0f;
static bool g_preview_zero_valid = false;
static int g_calibration_points = 0;
static uint32_t g_test_counter = 0;
static calibration_state_t g_calibration_state = CAL_STATE_IDLE;
static electromagnet_model_t g_electromagnet_model = {0};
static electromagnet_premodel_t g_electromagnet_premodel = {0};
static electromagnet_contact_points_t g_electromagnet_contact_points = {0};
static test_session_t g_test_session = {0};

static inline float calculate_load_signal(float zero_voltage, float measured_voltage);
static esp_err_t save_electromagnet_premodel_to_nvs(void);
static esp_err_t electromagnet_premodel_set(uint32_t move_threshold_duty, uint32_t contact_threshold_duty, float full_scale_mass_g);
static esp_err_t electromagnet_premodel_clear(void);

static inline float load_cell_full_scale_voltage(void)
{
    return (LOAD_CELL_SENSITIVITY_MV_V / 1000.0f) * LOAD_CELL_EXCITATION_V * LOAD_CELL_HARDWARE_GAIN;
}

static inline float load_cell_nominal_kg_per_v(void)
{
    const float full_scale_voltage = load_cell_full_scale_voltage();
    if (!(full_scale_voltage > 0.0f) || !isfinite(full_scale_voltage)) {
        return 0.0f;
    }

    return LOAD_CELL_CAPACITY_KG / full_scale_voltage;
}

static inline float load_cell_current_kg_per_v(void)
{
    if (g_calibration.a > 0.0f && isfinite(g_calibration.a)) {
        return g_calibration.a;
    }

    return load_cell_nominal_kg_per_v();
}

static void calibration_invalidate_model(void)
{
    g_calibration.valid = false;
    g_calibration.a = load_cell_nominal_kg_per_v();
    g_calibration.b = 1.0f;
    g_calibration.cal_mass_1 = 0.0f;
    g_calibration.cal_mass_2 = 0.0f;
    g_calibration.cal_diff_1 = 0.0f;
    g_calibration.cal_diff_2 = 0.0f;
}

static float ads1219_measure_configured(
    uint8_t mux_sel,
    uint8_t gain_sel,
    uint8_t rate_sel,
    float vref,
    uint8_t reference,
    int target_samples
)
{
    ads1219_configureMeasurement(
        ADS1219_ADRESS,
        mux_sel,
        gain_sel,
        rate_sel,
        ADS1219_CONV_MODE_SINGLE,
        reference
    );

    vTaskDelay(pdMS_TO_TICKS(2));

    const float gain = (gain_sel == ADS1219_GAIN_4) ? 4.0f : 1.0f;
    float sum = 0.0f;
    bool skip_first_valid = true;
    int valid_samples = 0;
    const int minimum_valid_samples = (target_samples >= 4) ? (target_samples / 2) : 1;

    for (int attempt = 0; attempt < (target_samples + 1) * 3 && valid_samples < target_samples; ++attempt) {
        ads1219_startSync(ADS1219_ADRESS);
        const int32_t raw = ads1219_read(ADS1219_ADRESS);
        if (raw == 0x7FFFFFFF) {
            vTaskDelay(pdMS_TO_TICKS(2));
            continue;
        }

        if (skip_first_valid) {
            skip_first_valid = false;
            continue;
        }

        const float voltage = (raw / 8388608.0f) * vref;
        sum += voltage / gain;
        valid_samples++;
    }

    if (valid_samples < minimum_valid_samples) {
        return NAN;
    }

    return sum / (float)valid_samples;
}

static float ads1219_measure(uint8_t mux_sel, uint8_t gain_sel, float vref, uint8_t reference)
{
    return ads1219_measure_configured(
        mux_sel,
        gain_sel,
        ADS1219_DATA_RATE_20SPS,
        vref,
        reference,
        AVG_SAMPLES
    );
}

static float ads1219_measure_fast(uint8_t mux_sel, uint8_t gain_sel, float vref, uint8_t reference)
{
    return ads1219_measure_configured(
        mux_sel,
        gain_sel,
        ADS1219_DATA_RATE_330SPS,
        vref,
        reference,
        FAST_AVG_SAMPLES
    );
}

static float set_zero(int8_t type, int8_t gain, float vref)
{
    float acc = 0.0f;

    for (int i = 0; i < ZERO_AVG_SAMPLES; ++i) {
        acc += ads1219_measure((uint8_t)type, (uint8_t)gain, vref, ADS1219_VREF_EXTERNAL);
        vTaskDelay(pdMS_TO_TICKS(10));
    }

    return acc / (float)ZERO_AVG_SAMPLES;
}

static float set_zero_fast(int8_t type, int8_t gain, float vref)
{
    float acc = 0.0f;

    for (int i = 0; i < FAST_ZERO_AVG_SAMPLES; ++i) {
        acc += ads1219_measure_fast((uint8_t)type, (uint8_t)gain, vref, ADS1219_VREF_EXTERNAL);
        vTaskDelay(pdMS_TO_TICKS(2));
    }

    return acc / (float)FAST_ZERO_AVG_SAMPLES;
}

static float calibration_average_zero(void)
{
    float acc = 0.0f;

    for (int i = 0; i < CAL_STAGE_MEASUREMENTS; ++i) {
        acc += set_zero_fast(ADS1219_MEAS_SINGLE_2, ADS1219_GAIN_4, VREF_EXT);
        vTaskDelay(pdMS_TO_TICKS(4));
    }

    return acc / (float)CAL_STAGE_MEASUREMENTS;
}

static float calibration_average_point(void)
{
    float acc = 0.0f;

    for (int i = 0; i < CAL_STAGE_MEASUREMENTS; ++i) {
        const float relative = ads1219_measure_fast(
            ADS1219_MEAS_SINGLE_2,
            ADS1219_GAIN_4,
            VREF_EXT,
            ADS1219_VREF_EXTERNAL
        );
        acc += calculate_load_signal(g_calibration_zero, relative);
        vTaskDelay(pdMS_TO_TICKS(4));
    }

    return acc / (float)CAL_STAGE_MEASUREMENTS;
}

static float sensor_average_voltage(void)
{
    float acc = 0.0f;

    for (int i = 0; i < CAL_STAGE_MEASUREMENTS; ++i) {
        acc += ads1219_measure_fast(
            ADS1219_MEAS_DIFF_01,
            ADS1219_GAIN_1,
            VREF_EXT,
            ADS1219_VREF_EXTERNAL
        );
        vTaskDelay(pdMS_TO_TICKS(4));
    }

    return acc / (float)CAL_STAGE_MEASUREMENTS;
}

/**
 * @brief Returns the absolute load-cell signal relative to the stored zero.
 */
static inline float calculate_load_signal(float zero_voltage, float measured_voltage)
{
    return fabsf(measured_voltage - zero_voltage);
}

static inline float calculate_load(float diff_voltage)
{
    const float signal_voltage = fabsf(diff_voltage);
    if (!(signal_voltage > 0.0f) || !isfinite(signal_voltage)) {
        return 0.0f;
    }

    const float mass_kg = load_cell_current_kg_per_v() * signal_voltage;

    if (!isfinite(mass_kg) || mass_kg < 0.0f) {
        return 0.0f;
    }

    return mass_kg;
}

static inline float calculate_resistance_raw(float voltage)
{
    return (voltage * R1) / (V_SUPPLY - voltage);
}

static inline float calculate_resistance(float voltage)
{
    return calculate_resistance_raw(voltage) * g_sensor_calibration.factor;
}

static void electromagnet_apply_duty(uint32_t active_duty)
{
    if (active_duty > ELECTROMAGNET_PWM_MAX_DUTY) {
        active_duty = ELECTROMAGNET_PWM_MAX_DUTY;
    }

    const uint32_t hardware_duty = ELECTROMAGNET_PWM_MAX_DUTY - active_duty;
    ledc_set_duty(ELECTROMAGNET_PWM_MODE, ELECTROMAGNET_PWM_CHANNEL, hardware_duty);
    ledc_update_duty(ELECTROMAGNET_PWM_MODE, ELECTROMAGNET_PWM_CHANNEL);
}

static void electromagnet_off(void)
{
    electromagnet_apply_duty(0);
}

static void electromagnet_init(void)
{
    const ledc_timer_config_t timer_config = {
        .speed_mode = ELECTROMAGNET_PWM_MODE,
        .duty_resolution = ELECTROMAGNET_PWM_RESOLUTION,
        .timer_num = ELECTROMAGNET_PWM_TIMER,
        .freq_hz = ELECTROMAGNET_PWM_FREQ_HZ,
        .clk_cfg = LEDC_AUTO_CLK,
        .deconfigure = false,
    };
    ESP_ERROR_CHECK(ledc_timer_config(&timer_config));

    const ledc_channel_config_t channel_config = {
        .gpio_num = MOSFET_PIN,
        .speed_mode = ELECTROMAGNET_PWM_MODE,
        .channel = ELECTROMAGNET_PWM_CHANNEL,
        .intr_type = LEDC_INTR_DISABLE,
        .timer_sel = ELECTROMAGNET_PWM_TIMER,
        .duty = ELECTROMAGNET_PWM_MAX_DUTY,
        .hpoint = 0,
        .flags = {
            .output_invert = 0,
        },
    };
    ESP_ERROR_CHECK(ledc_channel_config(&channel_config));

    electromagnet_off();
}

static void test_session_reset(void)
{
    memset(&g_test_session, 0, sizeof(g_test_session));
}

static void electromagnet_premodel_reset_defaults(void)
{
    g_electromagnet_premodel.valid = false;
    g_electromagnet_premodel.move_threshold_duty = 0;
    g_electromagnet_premodel.contact_threshold_duty = 0;
    g_electromagnet_premodel.full_scale_mass_g = LOAD_CELL_CAPACITY_KG * 1000.0f;
}

static void electromagnet_contact_points_reset_defaults(void)
{
    memset(&g_electromagnet_contact_points, 0, sizeof(g_electromagnet_contact_points));
    g_electromagnet_contact_points.point_count = ELECTROMAGNET_CONTACT_POINT_DEFAULT_COUNT;
    g_electromagnet_contact_points.start_pct = ELECTROMAGNET_CONTACT_POINT_DEFAULT_START_PCT;
    g_electromagnet_contact_points.end_pct = ELECTROMAGNET_CONTACT_POINT_DEFAULT_END_PCT;
}

static uint8_t electromagnet_contact_point_sanitize_state(uint8_t state)
{
    return (state <= 3U) ? state : 0U;
}

static uint8_t electromagnet_contact_point_count(void)
{
    if (
        g_electromagnet_contact_points.point_count == 0U ||
        g_electromagnet_contact_points.point_count > ELECTROMAGNET_CONTACT_POINT_MAX_COUNT
    ) {
        return ELECTROMAGNET_CONTACT_POINT_DEFAULT_COUNT;
    }

    return g_electromagnet_contact_points.point_count;
}

static uint32_t electromagnet_contact_point_pct_to_duty(float pct)
{
    if (!isfinite(pct) || pct < 0.0f || pct > 100.0f) {
        return 0U;
    }

    const uint32_t duty = (uint32_t)lrintf((pct * (float)ELECTROMAGNET_PWM_MAX_DUTY) / 100.0f);
    if (duty >= ELECTROMAGNET_PWM_MAX_DUTY) {
        return ELECTROMAGNET_PWM_MAX_DUTY - 1U;
    }

    return duty;
}

static float electromagnet_contact_point_slot_to_pct(uint32_t slot)
{
    const uint8_t point_count = electromagnet_contact_point_count();
    if (point_count <= 1U) {
        return g_electromagnet_contact_points.start_pct;
    }

    const float progress = (float)slot / (float)(point_count - 1U);
    return g_electromagnet_contact_points.start_pct +
           (g_electromagnet_contact_points.end_pct - g_electromagnet_contact_points.start_pct) * progress;
}

static esp_err_t save_electromagnet_contact_points_to_nvs(void)
{
    nvs_handle_t handle;
    esp_err_t err = nvs_open("piezo", NVS_READWRITE, &handle);
    if (err != ESP_OK) {
        return err;
    }

    err = nvs_set_blob(handle, "mag_ct_pts", &g_electromagnet_contact_points, sizeof(g_electromagnet_contact_points));
    if (err == ESP_OK) {
        err = nvs_set_u8(handle, "mag_ct_ver", ELECTROMAGNET_CONTACT_POINTS_VERSION);
    }
    if (err == ESP_OK) {
        err = nvs_commit(handle);
    }

    nvs_close(handle);
    return err;
}

static esp_err_t load_electromagnet_contact_points_from_nvs(void)
{
    nvs_handle_t handle;
    esp_err_t err = nvs_open("piezo", NVS_READONLY, &handle);
    if (err != ESP_OK) {
        electromagnet_contact_points_reset_defaults();
        return err;
    }

    uint8_t version = 0;
    err = nvs_get_u8(handle, "mag_ct_ver", &version);
    if (err != ESP_OK || version != ELECTROMAGNET_CONTACT_POINTS_VERSION) {
        nvs_close(handle);
        electromagnet_contact_points_reset_defaults();
        return ESP_ERR_NVS_NOT_FOUND;
    }

    size_t size = sizeof(g_electromagnet_contact_points);
    err = nvs_get_blob(handle, "mag_ct_pts", &g_electromagnet_contact_points, &size);
    nvs_close(handle);
    if (err != ESP_OK || size != sizeof(g_electromagnet_contact_points)) {
        electromagnet_contact_points_reset_defaults();
        return (err != ESP_OK) ? err : ESP_FAIL;
    }

    if (
        !isfinite(g_electromagnet_contact_points.start_pct) ||
        !isfinite(g_electromagnet_contact_points.end_pct) ||
        g_electromagnet_contact_points.start_pct < 0.0f ||
        g_electromagnet_contact_points.start_pct > 100.0f ||
        g_electromagnet_contact_points.end_pct < g_electromagnet_contact_points.start_pct ||
        g_electromagnet_contact_points.end_pct > 100.0f
    ) {
        electromagnet_contact_points_reset_defaults();
        return ESP_FAIL;
    }

    for (size_t i = 0; i < ELECTROMAGNET_CONTACT_POINT_MAX_COUNT; ++i) {
        g_electromagnet_contact_points.state[i] =
            electromagnet_contact_point_sanitize_state(g_electromagnet_contact_points.state[i]);
    }

    return ESP_OK;
}

static esp_err_t electromagnet_contact_points_clear(void)
{
    electromagnet_contact_points_reset_defaults();
    return save_electromagnet_contact_points_to_nvs();
}

static esp_err_t electromagnet_contact_points_recompute_premodel(float full_scale_mass_g)
{
    int move_slot = -1;
    int contact_slot = -1;
    const uint8_t point_count = electromagnet_contact_point_count();

    for (int i = 0; i < point_count; ++i) {
        const uint8_t state = electromagnet_contact_point_sanitize_state(g_electromagnet_contact_points.state[i]);
        if (move_slot < 0 && (state == 2U || state == 3U)) {
            move_slot = i;
        }
        if (contact_slot < 0 && state == 3U) {
            contact_slot = i;
        }
    }

    if (move_slot < 0) {
        g_electromagnet_premodel.valid = false;
        g_electromagnet_premodel.move_threshold_duty = 0U;
        g_electromagnet_premodel.contact_threshold_duty = 0U;
        g_electromagnet_premodel.full_scale_mass_g = full_scale_mass_g;
        return save_electromagnet_premodel_to_nvs();
    }

    if (contact_slot < 0) {
        contact_slot = move_slot;
    }

    const uint32_t move_duty = electromagnet_contact_point_pct_to_duty(
        electromagnet_contact_point_slot_to_pct((uint32_t)move_slot)
    );
    const uint32_t contact_duty = electromagnet_contact_point_pct_to_duty(
        electromagnet_contact_point_slot_to_pct((uint32_t)contact_slot)
    );

    return electromagnet_premodel_set(move_duty, contact_duty, full_scale_mass_g);
}

static esp_err_t electromagnet_contact_point_set(uint32_t slot, uint8_t state, float full_scale_mass_g)
{
    if (
        slot >= electromagnet_contact_point_count() ||
        state > 3U ||
        !(full_scale_mass_g > 0.0f) ||
        !isfinite(full_scale_mass_g)
    ) {
        return ESP_ERR_INVALID_ARG;
    }

    g_electromagnet_contact_points.state[slot] = state;
    esp_err_t err = save_electromagnet_contact_points_to_nvs();
    if (err != ESP_OK) {
        return err;
    }

    return electromagnet_contact_points_recompute_premodel(full_scale_mass_g);
}

static esp_err_t electromagnet_contact_points_configure(uint32_t point_count, float start_pct, float end_pct)
{
    if (
        point_count == 0U ||
        point_count > ELECTROMAGNET_CONTACT_POINT_MAX_COUNT ||
        !isfinite(start_pct) ||
        !isfinite(end_pct) ||
        start_pct < 0.0f ||
        start_pct > 100.0f ||
        end_pct < start_pct ||
        end_pct > 100.0f
    ) {
        return ESP_ERR_INVALID_ARG;
    }

    g_electromagnet_contact_points.point_count = (uint8_t)point_count;
    g_electromagnet_contact_points.start_pct = start_pct;
    g_electromagnet_contact_points.end_pct = end_pct;
    for (size_t i = 0; i < ELECTROMAGNET_CONTACT_POINT_MAX_COUNT; ++i) {
        g_electromagnet_contact_points.state[i] = 0U;
    }

    esp_err_t err = save_electromagnet_contact_points_to_nvs();
    if (err == ESP_OK) {
        err = electromagnet_premodel_clear();
    }
    return err;
}
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
void app_main(void)
{
    initUART();
    initI2C();
    ADS1219_init(ADS1219_RST_PIN, ADS1219_DRDY_PIN);
    gpio_set_level(ADS1219_RST_PIN, 1);
    electromagnet_init();

    esp_err_t err = nvs_flash_init();
    if (err == ESP_ERR_NVS_NO_FREE_PAGES || err == ESP_ERR_NVS_NEW_VERSION_FOUND) {
        ESP_ERROR_CHECK(nvs_flash_erase());
        err = nvs_flash_init();
    }
    ESP_ERROR_CHECK(err);

    const bool load_calibration_ok = (load_calibration_from_nvs() == ESP_OK);
    if (!load_calibration_ok) {
        calibration_reset_session();
    }

    sensor_calibration_reset_defaults();
    load_sensor_calibration_from_nvs();
    electromagnet_model_reset_defaults();
    load_electromagnet_model_from_nvs();
    electromagnet_contact_points_reset_defaults();
    load_electromagnet_contact_points_from_nvs();
    electromagnet_premodel_reset_defaults();
    load_electromagnet_premodel_from_nvs();
    test_session_reset();
    write_line(load_calibration_ok ? "READY calibrated=1" : "READY calibrated=0");

    char line[128];
    while (1) {
        const int len = uart_read_line(line, sizeof(line), pdMS_TO_TICKS(1000));
        if (len <= 0) {
            continue;
        }
        handle_command(line);
    }
}

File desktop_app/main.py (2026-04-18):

from __future__ import annotations

import csv
import math
import queue
import statistics
import sys
import threading
import time
from dataclasses import dataclass
from datetime import datetime
from pathlib import Path

import serial
import serial.tools.list_ports
from PySide6.QtCore import QMarginsF, QRect, QRectF, QSize, QTimer, Qt
from PySide6.QtCharts import QChart, QChartView, QLineSeries, QScatterSeries, QValueAxis
from PySide6.QtGui import QColor, QPageLayout, QPageSize, QPainter, QPdfWriter, QPen, QPixmap
from PySide6.QtWidgets import (
    QApplication,
    QComboBox,
    QDialog,
    QDoubleSpinBox,
    QFileDialog,
    QFormLayout,
    QGroupBox,
    QGraphicsScene,
    QHBoxLayout,
    QHeaderView,
    QLabel,
    QLineEdit,
    QMainWindow,
    QMessageBox,
    QPushButton,
    QPlainTextEdit,
    QScrollArea,
    QSizePolicy,
    QSpinBox,
    QTableWidget,
    QTableWidgetItem,
    QVBoxLayout,
    QWidget,
)


BAUDRATE = 115200
CALIBRATION_STAGE_TIMEOUT = 90.0
HYSTERESIS_TRACE_POINTS = 24
APP_DIR = Path(__file__).resolve().parent
LOG_DIR = APP_DIR / "logs"
LOG_DIR.mkdir(exist_ok=True)


@dataclass
class CalibrationStatus:
    calibrated: bool
    nominal_kg_per_v: float = 0.0
    kg_per_v: float = 0.0
    correction: float = 1.0
    cal_mass: float = 0.0
    nominal_mass: float = 0.0
    cal_signal: float = 0.0
    cal_zero: float = 0.0
    sensor_calibrated: bool = False
    sensor_factor: float = 1.0
    sensor_ref: float = 0.0
    sensor_raw: float = 0.0
    sensor_voltage: float = 0.0
    mag_points: int = 0
    mag_model_min_g: float = 0.0
    mag_model_max_g: float = 0.0
    mag_pre_valid: bool = False
    mag_move: int = 0
    mag_move_pct: float = 0.0
    mag_contact: int = 0
    mag_contact_pct: float = 0.0
    mag_full_scale_g: float = 0.0
    mag_contact_count: int = 10
    mag_contact_start_pct: float = 95.5
    mag_contact_end_pct: float = 100.0
    mag_contact_states: str = ""


@dataclass
class LoadPreview:
    zero: float
    measured: float
    signal: float
    mass_kg: float
    mass_g: float


@dataclass
class MagnetMeasurement:
    pwm_duty: int
    pwm_percent: float
    hold_ms: int
    load_v: float
    zero_v: float
    relative_v: float
    mass_g: float
    resistance: float
    sensor_v: float
    points: int


@dataclass
class TestResult:
    idx: int
    mode: str
    phase: str
    cycle: int
    phase_point: int
    target_g: float
    pwm_duty: int
    pwm_percent: float
    load_v: float
    zero_v: float
    relative_v: float
    mass_g: float
    resistance: float
    sensor_v: float
    created_at: datetime


@dataclass
class TestSettings:
    mode: str
    sample_count: int
    start_mass_g: float = 0.0
    end_mass_g: float = 0.0
    hysteresis_points: int = 0


@dataclass
class MetricStats:
    mean: float
    min: float
    max: float
    std: float


@dataclass
class TrialSummary:
    started_at: datetime
    finished_at: datetime
    sample_count: int
    mass_stats: MetricStats | None
    resistance_stats: MetricStats | None
    csv_log_path: Path
    test_settings: TestSettings | None = None


class SerialProtocolError(RuntimeError):
    pass


def parse_key_value_line(line: str) -> dict[str, str]:
    parts = line.split()
    data: dict[str, str] = {}
    for token in parts[1:]:
        if "=" not in token:
            continue
        key, value = token.split("=", 1)
        data[key] = value
    return data


def calculate_stats(values: list[float]) -> MetricStats | None:
    valid_values = [value for value in values if not math.isnan(value)]
    if not valid_values:
        return None

    return MetricStats(
        mean=statistics.mean(valid_values),
        min=min(valid_values),
        max=max(valid_values),
        std=statistics.pstdev(valid_values) if len(valid_values) > 1 else 0.0,
    )


def mode_label(mode: str) -> str:
    if mode == "ramp":
        return "Narastajacy"
    if mode == "hysteresis":
        return "Histereza"
    return "Standardowy"


def stats_to_cells(stats: MetricStats | None) -> list[str]:
    if stats is None:
        return ["-", "-", "-", "-"]

    return [
        f"{stats.mean:.3f}",
        f"{stats.min:.3f}",
        f"{stats.max:.3f}",
        f"{stats.std:.3f}",
    ]


def format_duration(started_at: datetime, finished_at: datetime) -> str:
    total_seconds = max(0, int((finished_at - started_at).total_seconds()))
    hours, remainder = divmod(total_seconds, 3600)
    minutes, seconds = divmod(remainder, 60)

    if hours > 0:
        return f"{hours:02d}:{minutes:02d}:{seconds:02d}"
    return f"{minutes:02d}:{seconds:02d}"


def default_export_dir() -> Path:
    documents_dir = Path.home() / "Documents"
    if documents_dir.exists():
        return documents_dir
    return Path.home()
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

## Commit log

2025-11-10 Added Matlab and PCB V2.1 completed fw
    [DIP781W56P254L950H533Q8N.PcbLib, DIP794W53P254L959H508Q8N.PcbLib, EDI2CAP.CFG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]
2026-03-14 PCB v2.2
    [4040 Aluminum Extrusion Profile.SLDPRT, Część4.SLDPRT, Złożenie1.SLDASM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]
2026-04-17 feat: add nominal load-cell calibration flow
2026-04-17 fix: auto-start live preview and harden pdf export
    [main.py]
2026-04-18 feat: add ramp test mode with pwm learning
2026-04-18 feat: add advanced electromagnet calibration tools
2026-04-18 fix: suspend live preview during zero calibration
    [main.py]
2026-04-18 refactor: simplify calibration flow and speed preview
2026-04-18 fix: stabilize calibration dialog startup
    [main.py]
2026-04-18 fix: avoid GUI updates from calibration worker threads
    [main.py]
2026-04-18 fix: open summary dialog after automatic test completion
    [main.py]
2026-04-18 feat: add point-by-point electromagnet contact calibration table
2026-04-18 feat: persist electromagnet contact calibration points
2026-04-18 refactor: make contact calibration grid configurable
2026-04-18 fix: preserve selected contact state during config sync
    [main.py]
2026-04-18 fix: enlarge firmware response buffer for status payload
    [main.c]
2026-04-18 fix: redefine hysteresis as repeated load-unload cycles
    [main.c, main.py]
2026-04-18 feat: add 10s pause between non-hysteresis samples
2026-04-18 fix: retry stalled test reads and keep partial summary
    [main.py]
2026-04-18 fix: return test done after final sample
    [main.c]
2026-04-19 chore: sync repository with current workspace layout
    [4040 Aluminum Extrusion Profile.SLDPRT, Część4.SLDPRT, ESP32-WROOM-32D-Assembly.STEP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]
